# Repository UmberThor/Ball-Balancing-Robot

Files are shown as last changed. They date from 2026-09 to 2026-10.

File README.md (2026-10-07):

# Ball Balancing Robot

A 3-DOF parallel platform that keeps a ball balanced in the center of a transparent plate. A camera looks at the plate from below and detects the position of the ball, a controller turns the ball position error into a desired plate slope, and the inverse kinematics turns that slope into three servo angles.

<p align="center">
  The robot balancing a ball
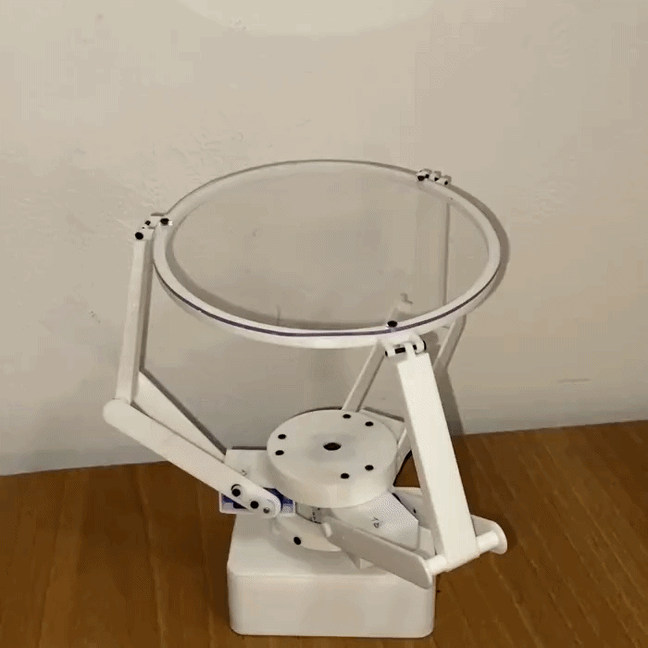
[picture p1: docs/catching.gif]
The robot catching a ball
  
  <br>
  <em>On the left the robot balancing a ball, on the right the robot catching a ball (0.5 speed)</em>
</p>

Three controllers are tested: a PID controller, an LQR controller and an RL controller.

The repository is organized as follows:

```
Ball-Balancing-Robot/
├── scripts/                          code that runs on the robot
│   ├── ball_balancer.py              main loop
│   ├── hardware.py                   servos and camera
│   ├── vision.py                     ball detection
│   ├── kalman.py                     estimate of the error and of its velocity
│   ├── control.py                    PID, LQR and RL controllers
│   ├── kinematics.py                 inverse kinematics
│   └── policy.npz                    weights of the RL policy
├── reinforcement_learning/           simulation and training of the RL controller
│   ├── ball_balancer.xml             MuJoCo model of the plate and the ball
│   ├── ball_balancer_env.py          Gymnasium environment
│   ├── action_limits.ipynb           computation of the action limit
│   ├── reinforcement_learning.ipynb  training of the policy
│   └── environment.yml               conda environment
├── matlab/                           offline references, not run on the robot
│   ├── inverse_kinematics.m          inverse kinematics and plot of the assembly
│   └── linear_quadratic_control.m    computation of the LQR gain
├── metrics/                          evaluation of the controllers
│   ├── metrics.py                    metrics of the logged runs
│   └── log_*.csv                     logged runs
└── 3d files/                         printed parts
```

This README is organized in the following sections:

| § | Section |
|---|---|
| 1 | Running the code |
| 2 | Mechanical design |
| 3 | Electronics |
| 4 | 3D print and assembly |
| 5 | Inverse kinematics |
| 6 | Actuation |
| 7 | Ball detection |
| 8 | Ball model |
| 9 | Kalman filter |
| 10 | PID control |
| 11 | LQR control |
| 12 | Reinforcement learning control |
| 13 | Evaluation metrics |
| 14 | Future developments |
| 15 | Credits |

## 1. Running the code

The code runs on the Raspberry Pi of §3, with Raspberry Pi OS. The dependencies are installed with `apt`, and the `pigpio` daemon must be started before the script.

```bash
sudo apt install git python3-picamera2 python3-opencv python3-numpy pigpio python3-pigpio
git clone https://github.com/UmberThor/Ball-Balancing-Robot.git
cd Ball-Balancing-Robot/scripts
sudo pigpiod
python3 ball_balancer.py --pid
```

Exactly one control mode must be selected:

| Flag | Control |
|---|---|
| `--pid` | Proportional Integral Derivative Controller, §10 |
| `--lqr` | Linear Quadratic Regulator Controller, §11 |
| `--rl` | Reinforcement Learning, §12|

The `--gui` flag is optional and opens a window that shows the ball detection of §7, and requires a display.

The `--kalman` flag is optional and feeds the controller with the error and the velocity estimated by the Kalman filter of §9 instead of the measured error and its finite difference. 

The `--log` flag is optional and, when the script stops, saves to `log_<mode>_<date>_<time>.csv` the time, the measured error and the control action of every frame with the ball. 

The script is stopped with Ctrl+C, or with `q` on the window when `--gui` is set.

---

## 2. Mechanical design

The robot is modeled in Fusion 360.

<p align="center">
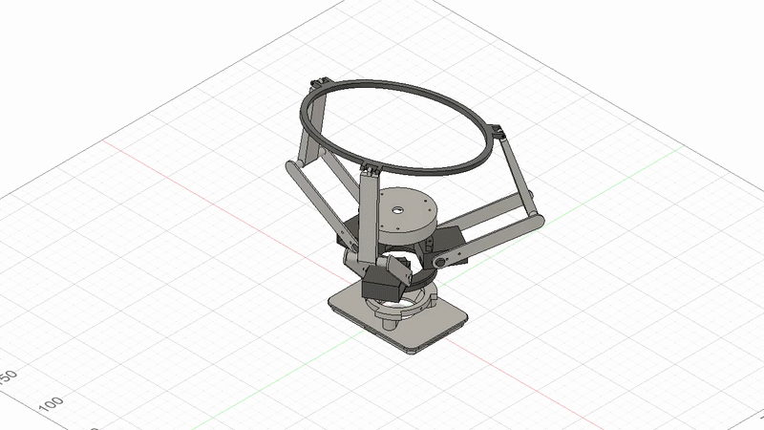
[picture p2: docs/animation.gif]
  
  <br>
  <em>The assembly moving in Fusion 360</em>
</p>

The robot has a fixed base and a moving plate, a printed ring that holds a transparent plexiglass disc. Three identical arms, located 120° apart, connect the base to the plate. Each arm is a two-link RRU chain, so the robot as a whole is a **3-RRU** parallel manipulator: revolute at the shoulder, revolute at the elbow, universal at the ball joint. The shoulder joint is **active**, driven by a servo; the elbow and the ball joint are **passive**. Each arm is carried by the servo horn alone, so it hangs on one side of the servo.

The robot axes have the origin at the center of the base, at the height of the servo shafts, with $z$ vertical and upward, and $x$ horizontal, from the shoulder of arm 1 through the center of the base. Measured from $x$ towards $y$, arm 1 is at 180°, arm 2 at 300° and arm 3 at 60°.

The dimensions of the mechanism, measured on the Fusion 360 model, are:

| Constant | Meaning | Value |
|---|---|---|
| $R_b$ | radius of the base circle, on which the shoulders lie | 28.65 mm |
| $R_p$ | radius of the plate circle, on which the ball joints lie | 84.00 mm |
| $L_1$ | length of the upper link, from the elbow to the ball joint | 80 mm |
| $L_2$ | length of the lower link, from the shoulder to the elbow | 80 mm |

All the printed parts are in the `3d files` folder:

| File | Part | Qty |
|---|---|---|
| `raspberry_bottom.stl` | lower half of the Raspberry Pi case, the foot of the robot | 1 |
| `raspberry_top.stl` | upper half of the case, modified to carry the servo base | 1 |
| `camera_cover.stl` | cover that holds the camera pointing up at the plate | 1 |
| `motor_base.stl` | base that holds the three servos 120° apart | 1 |
| `link_lower_half.stl` | half of the lower link, from the servo to the elbow | 6 |
| `link_lower_connector.stl` | connector of the two halves of the lower link | 3 |
| `link_upper.stl` | upper link, from the elbow to the plate | 3 |
| `plate.stl` | ring that holds the transparent plate | 1 |

> **On the ball joints.** They are *modeled* as ball joints but the printed robot realizes them as a screw through a clearance hole. That is nominally a pin joint; the extra rotational freedom comes from the clearance, so it is a compliant stand-in for a spherical pair rather than a true ball joint.

<p align="center">
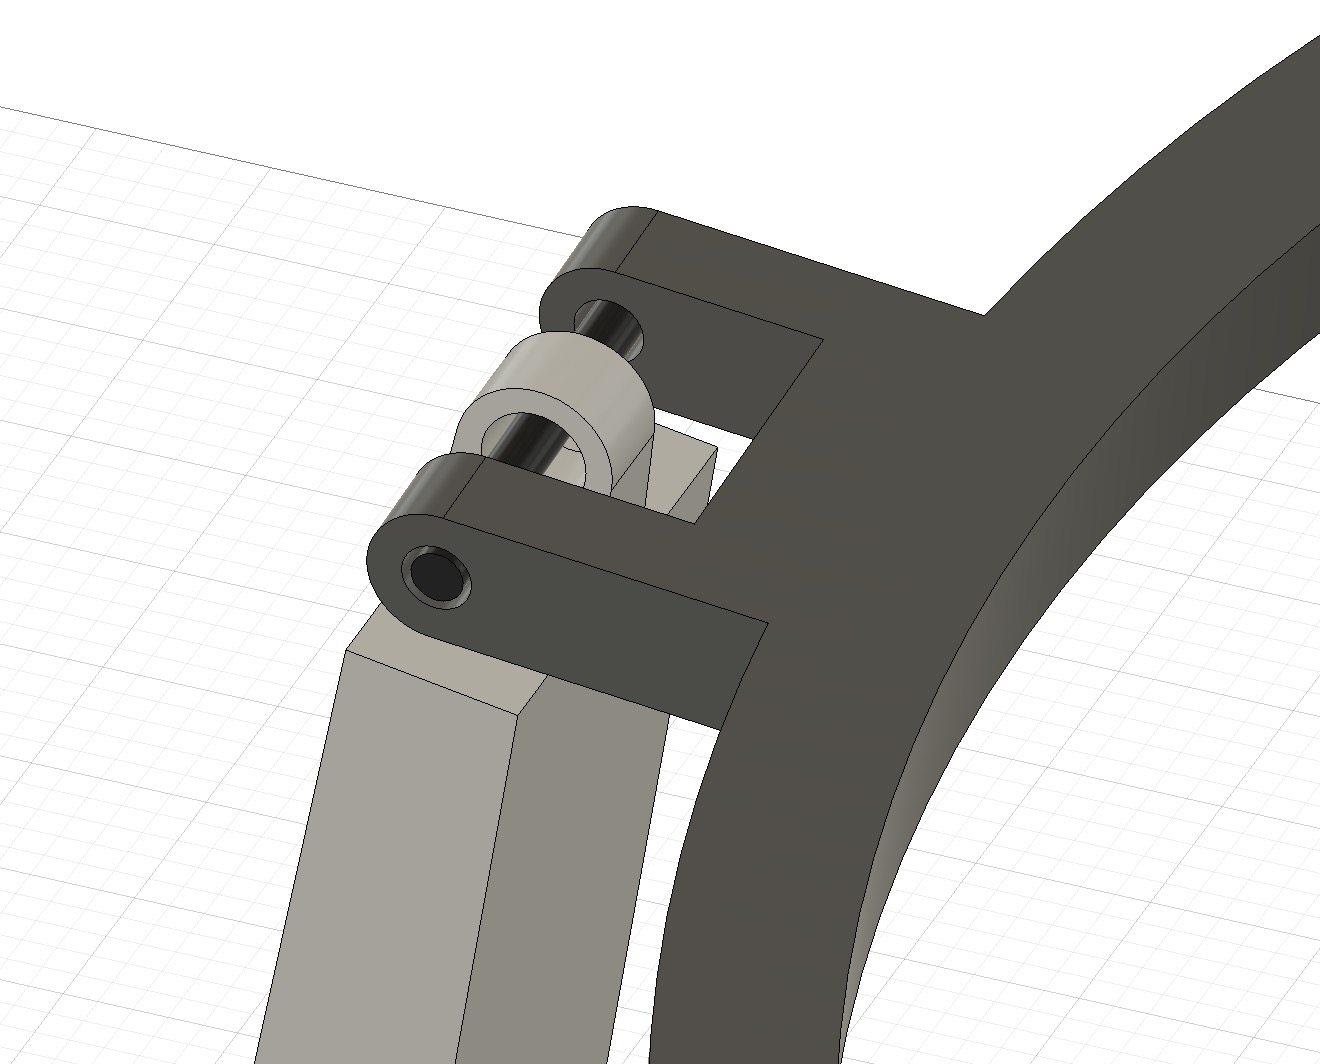
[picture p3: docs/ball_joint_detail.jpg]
  
  <br>
  <em>The joint connecting the upper link with the plate</em>
</p>

In the first version of the robot the links were about half as long as the current ones. The plate was then so close to the camera that the ball covered almost the entire field of view, and its position was detected poorly. The links have therefore been made longer, until the distance between the camera and the plate was enough for a reliable detection, but not so long as to increase excessively the moment arm, and with it the torque the servos need to tilt the plate.

## 3. Electronics

The electronics are kept as simple as possible: a Raspberry Pi 4 Model B, three SG90 servos, a 5 megapixel camera module that plugs into the CSI port of the Raspberry Pi, and male-female jumper cables.

Each servo has three wires: signal, 5V and ground. The signal wires go to three GPIO pins of the Raspberry Pi, and servo $i$ drives arm $i$:

| Servo | GPIO (BCM) |
|---|---|
| 1 | 13 |
| 2 | 18 |
| 3 | 12 |

The numbers are the BCM numbering used by `pigpio`, not the position of the pin on the header. This is also the order declared in `scripts/hardware.py`, so keeping it makes the code work as it is.

The three grounds go to three distinct GND pins. The 5V pins of the Raspberry Pi are only two, so one servo takes one of them, while the other two share the second one through a jumper cable with one female and two male ends, made by hand.

<p align="center">
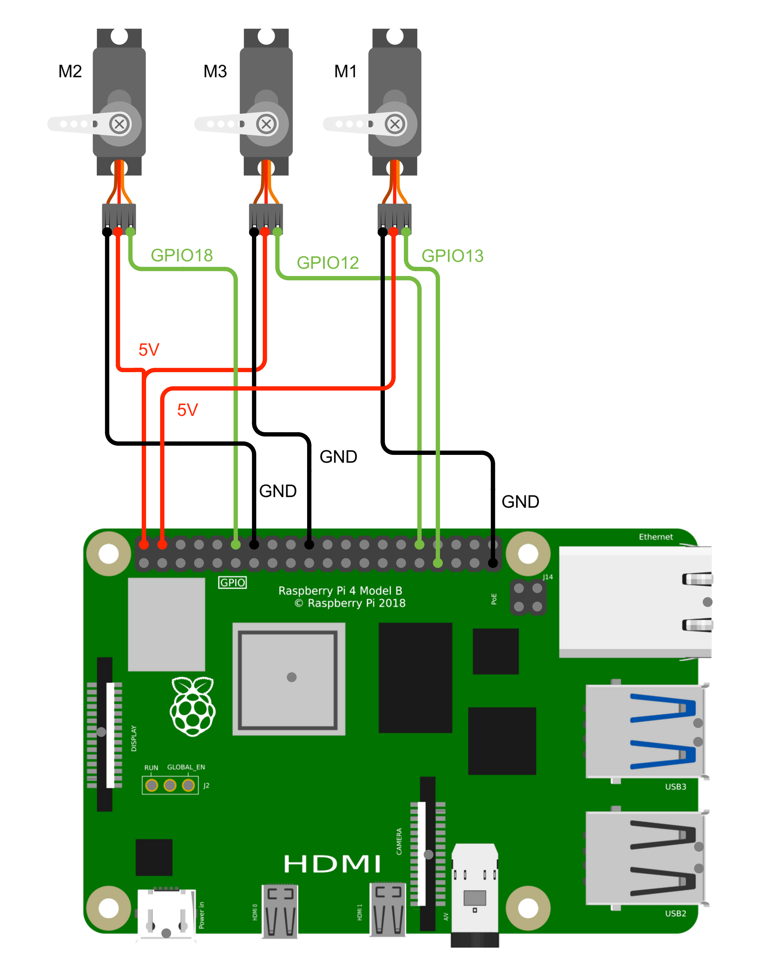
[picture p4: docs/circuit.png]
The three servos wired to the GPIO header of the Raspberry Pi
  
  <br>
  <em>Wiring of the three servos to the pins of the Raspberry Pi header</em>
</p>

> **On the power supply.** The Raspberry Pi is powered by its own USB-C cable, which outputs 5.1 V at 3 A, and the three servos draw from that same rail. This is not the ideal way to feed three servos: a proper build would power them from a dedicated power supply module, leaving the 5V rail of the Raspberry Pi to the Raspberry Pi alone. Compactness was one of the goals of this project, so the current version accepts the compromise.

## 4. 3D print and assembly

### 4.1 3D print

The parts are printed in PLA with the default settings of the slicer. The loads on the structure are low, so orientation and infill are not critical. `motor_base.stl` and `raspberry_top.stl` require supports, `raspberry_bottom.stl` prints better with them but is acceptable without, and the other parts do not need them.

### 4.2 Assembly

Besides the printed parts, the robot needs:

- [Raspberry Pi 4 Model B](https://www.amazon.it/-/en/Raspberry-Pi-W128431608-Model-2GB/dp/B09TTNPB4J)
- [5 megapixel CSI camera module](https://www.amazon.it/dp/B0DKNBP41T?ref=ppx_yo2ov_dt_b_fed_asin_title)
- [30 cm wide flex cable](https://www.amazon.it/dp/B075PBTQPG?ref=ppx_yo2ov_dt_b_fed_asin_title&th=1) for the camera
- 9 male-female jumper cables
- 3 SG90 servos, with their horns and the small screw that fixes each horn to its shaft
- 3 M2 screws 15 mm long, for the ball joints between the upper links and the ring
- 9 M2 screws 4 mm long, six to fix the lower links to the servo horns, two per horn, and three to fix the plate to the ring
- 9 M2 screws 10 mm long, six between the camera cover and the servo base and three between the servo base and the top half of the Raspberry Pi case
- a plexiglass disc of 150 mm of diameter for the plate
- a ping pong ball, pink in this build: a ball of a different color requires the detection of §7 to be adjusted

The horns are mounted with the servos at 90°: each servo is driven to that position before its horn is fixed to the shaft, aligned with the body of the servo. The alignment is necessarily approximate: what is left of it is corrected in software by the constants `OFFSETS` of `scripts/hardware.py`, `[0, -5, -5]` in this build, which are added in degrees to the angles commanded to the three servos.

<p align="center">
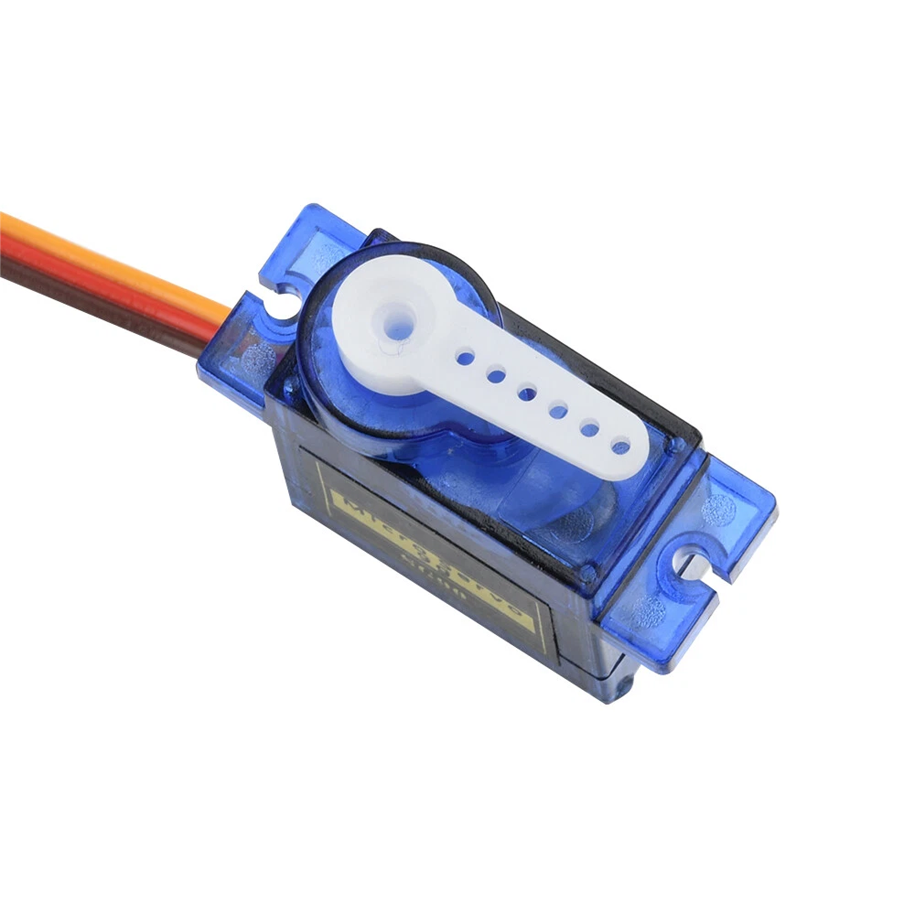
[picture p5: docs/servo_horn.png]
Servo horn aligned with the body of the servo
  
  <br>
  <em>Position of the horn at 90°</em>
</p>

## 5. Inverse kinematics

Reference implementation: `matlab/inverse_kinematics.m`.

### 5.1 Problem statement

In the model, the plate is a rigid disc whose center is constrained to the vertical $z$ axis. It can therefore only *tilt* and *rise*, which is exactly 3 DOF.

The **pose** of the plate is given by:

- $\mathbf{n} = [n_x,\ n_y,\ n_z]^T$, the unit normal of the plate,
- $h$, the height of the center of the plate $(0, 0, h)$, in mm.

The **configuration** of the robot is given by the three servo angles $q_1, q_2, q_3$. The inverse kinematics computes the configuration from the pose.

### 5.2 Geometry

| Point | Meaning |
|---|---|
| $\mathbf{M}_i$ | coordinates of the $i$-th shoulder, on the base circle of radius $R_b$ |
| $\mathbf{P}_i$ | coordinates of the $i$-th elbow, which connects the two links |
| $\mathbf{B}_i$ | coordinates of the $i$-th ball joint, on the plate circle of radius $R_p$ |

The constants $R_b$, $R_p$, $L_1$ and $L_2$ are the ones of §2. Running `inverse_kinematics.m` draws the whole assembly for a given pose:

<p align="center">
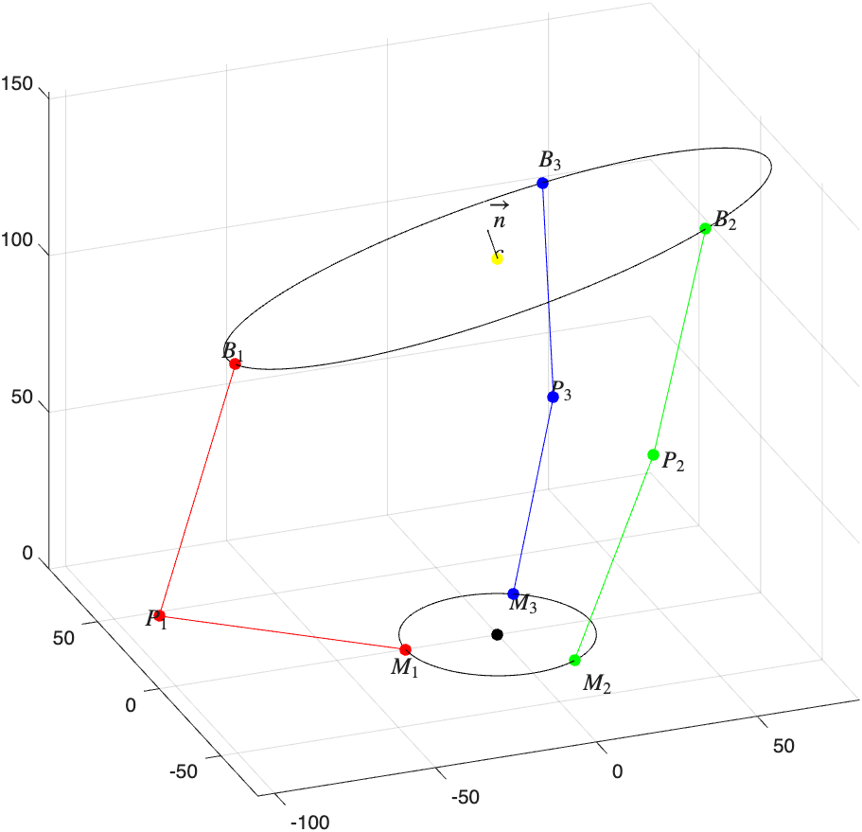
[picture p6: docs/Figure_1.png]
  
  <br>
  <em>The assembly for <b>n</b> = [&minus;0.25, 0.33, 1]<sup>T</sup>, plotted by <code>inverse_kinematics.m</code>: base circle and the three shoulders, plate circle with its normal arrow, ball joints, elbows and both links of every arm, red / green / blue for arms 1 / 2 / 3</em>
</p>

### 5.3 Planes

Each arm ($\mathbf{M}_i$, $\mathbf{P}_i$ and $\mathbf{B}_i$) is confined to a fixed vertical plane. In coordinates, that plane is simply

$$y = E_i\  x .$$

where $E_i = \frac{M_{iy}}{M_{ix}}$. Under this consideration, the entire 3D problem collapses into three independent 2D problems, one per plane.

<p align="center">
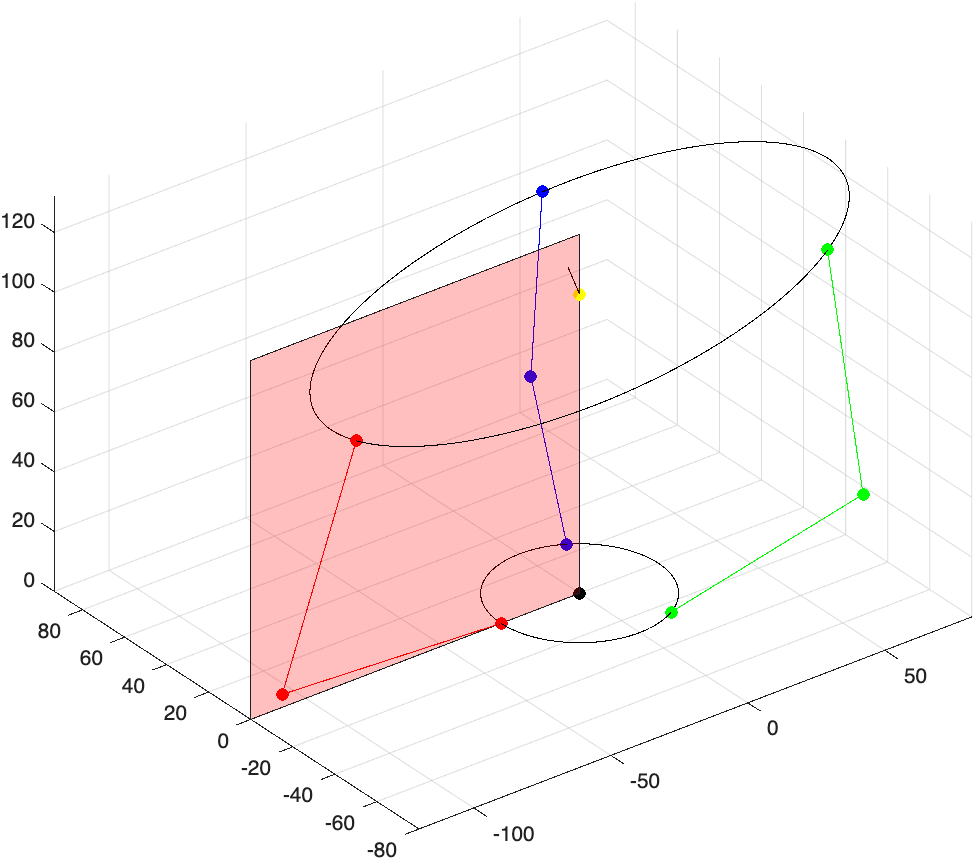
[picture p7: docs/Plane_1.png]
Plane y = 0 containing arm 1
  
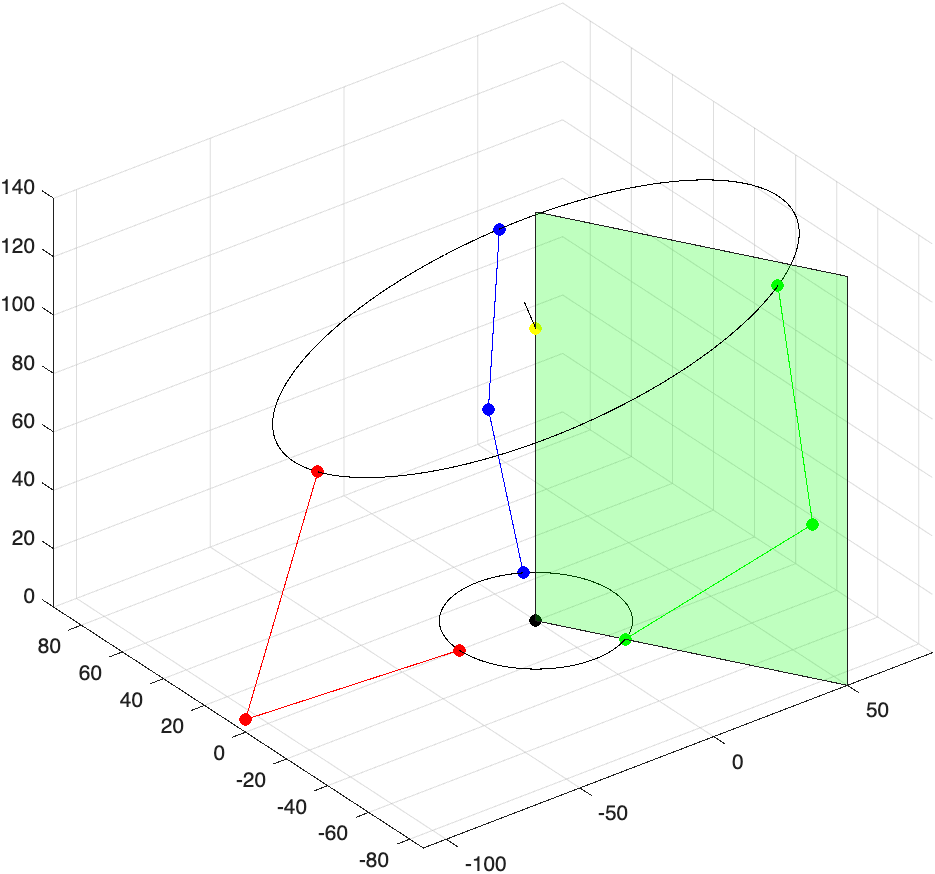
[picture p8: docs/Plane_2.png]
Plane y = -sqrt(3) x containing arm 2
  
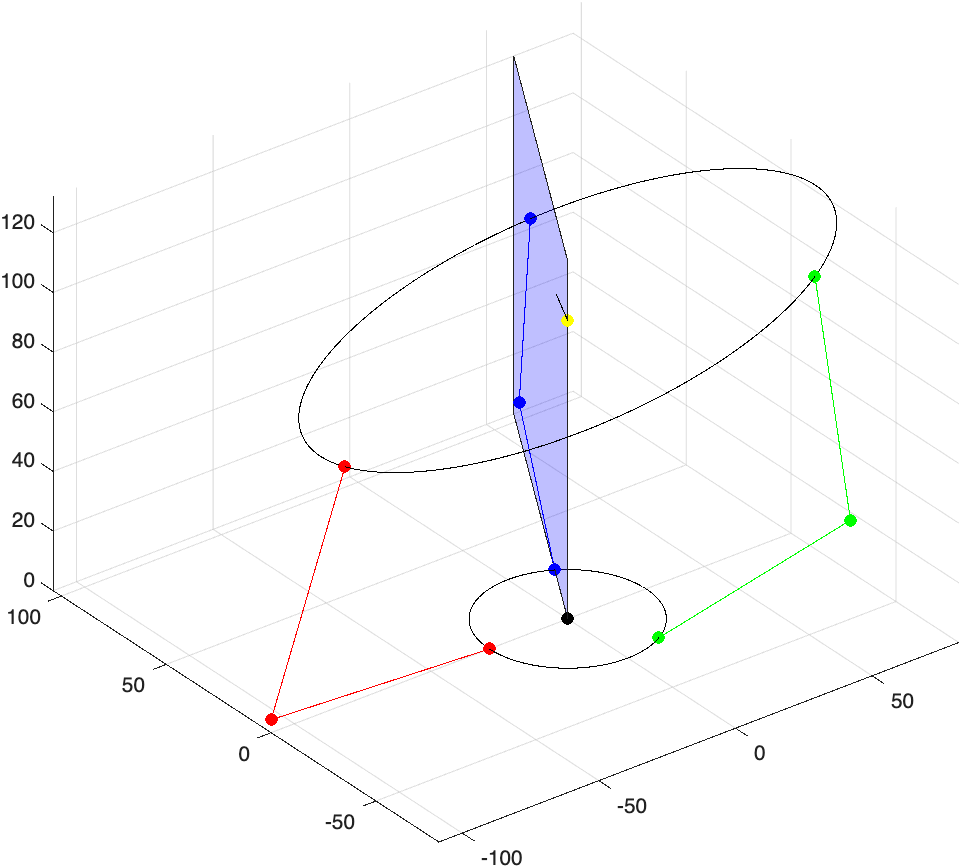
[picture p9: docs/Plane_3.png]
Plane y = sqrt(3) x containing arm 3
  
  <br>
  <em>The three arm planes: arm 1 is red, arm 2 is green and arm 3 is blue.<br>Whatever the pose of the plate, each arm and the ball joint it drives stay in their own plane.</em>
</p>

The shoulders lie on the base circle of radius $R_b$, at the angles of §2, so:

| Arm | $\mathbf{M}_i$ | $E_i$
|-----|---|---|
| 1 | $(-R_b,\ 0,\ 0)$ | $0$
| 2 | $(R_b/2,\ -\tfrac{\sqrt3}{2}R_b,\ 0)$ | $-\sqrt3$ |
| 3 | $(R_b/2,\ +\tfrac{\sqrt3}{2}R_b,\ 0)$ | $+\sqrt3$ |

### 5.4 Step 1 — Ball joints $\mathbf{B}_i$

$\mathbf{B}_i$ is the intersection of three conditions:

1. it lies in the plane of the plate
2. it lies in the arm plane
3. it lies on the circle of the ball joints

This leads to writing the system:

$$
\begin{cases}
n_x x + n_y y + n_z (z - h)= 0 \\
y = E_i x \\
x^2 + y^2 + (z - h)^2 = R_p^2
\end{cases}
$$

Substituting (2) into (1) gives the height along the plane as a function of $x$:

$$z = h - \frac{n_x + n_y E_i}{n_z}\ x$$

and substituting both into (3) leaves a pure quadratic in $x$:

$$x^2\left[1 + E_i^2 + \frac{(n_x + n_y E_i)^2}{n_z^2}\right] = R_p^2 .$$

Hence the closed form for any arm:

$$
x_i = s_i\ \frac{n_z R_p}{\sqrt{n_z^2\left(1 + E_i^2\right) + (n_x + n_y E_i)^2}},
\qquad y_i = E_i\ x_i,
\qquad z_i = h - \frac{n_x + n_y E_i}{n_z}\ x_i$$

where $s_i \in \lbrace -1, +1 \rbrace$ picks the one of the two points of the plate circle that is on the side of the shoulder; the other root is the diametrically opposite point of the circle.

Expanding for the three arms gives:

**Arm 1**: $E_1 = 0$, $s_1 = -1$:

$$\mathbf{B}_1 = \left(-\frac{n_z R_p}{\sqrt{n_x^2 + n_z^2}},\quad 0,\quad
h + \frac{n_x R_p}{\sqrt{n_x^2 + n_z^2}}\right)$$

**Arm 2**: $E_2 = -\sqrt3$, $s_2 = +1$:

$$\mathbf{B}_2 = \left(
\frac{n_z R_p}{\sqrt{4n_z^2 + \left(\sqrt3n_y - n_x\right)^2}},\quad
-\frac{\sqrt3\ n_z R_p}{\sqrt{4n_z^2 + \left(\sqrt3n_y - n_x\right)^2}},\quad
h + \frac{R_p\left(\sqrt3n_y - n_x\right)}{\sqrt{4n_z^2 + \left(\sqrt3n_y - n_x\right)^2}}
\right)$$

**Arm 3**: $E_3 = +\sqrt3$, $s_3 = +1$:

$$\mathbf{B}_3 = \left(
\frac{n_z R_p}{\sqrt{4n_z^2 + \left(\sqrt3n_y + n_x\right)^2}},\quad
+\frac{\sqrt3\ n_z R_p}{\sqrt{4n_z^2 + \left(\sqrt3n_y + n_x\right)^2}},\quad
h - \frac{R_p\left(\sqrt3n_y + n_x\right)}{\sqrt{4n_z^2 + \left(\sqrt3n_y + n_x\right)^2}}
\right)$$

Before solving for the elbow, the two-link chain must be able to span the gap between shoulder and ball joint. The triangle inequality gives, per arm,

$$|L_1 - L_2| < \lVert \mathbf{B}_i - \mathbf{M}_i \rVert < L_1 + L_2$$

If such condition fails, the requested pose $(\mathbf{n}, h)$ is simply not reachable.

### 5.5 Step 2 — Elbows $\mathbf{P}_i$

$\mathbf{P}_i$ is again the intersection of three conditions:

1. it is at distance $L_1$ from the ball joint
2. it is at distance $L_2$ from the shoulder
3. it lies in the arm plane

This leads to writing the system:

$$
\begin{cases}
(x - B_{ix})^2 + (y - B_{iy})^2 + (z - B_{iz})^2 = L_1^2 \\
(x - M_{ix})^2 + (y - M_{iy})^2 + (z - M_{iz})^2 = L_2^2 \\
y = E_i x
\end{cases}
$$

Subtracting sphere (2) from sphere (1) kills every quadratic term and leaves a plane, which solved for $z$ reads

$$z = \lambda_i + \mu_ix + \nu_iy$$

with

$$
\begin{gathered}
\lambda_i = \frac{L_1^2 - L_2^2 + \left(M_{ix}^2 - B_{ix}^2\right) + \left(M_{iy}^2 - B_{iy}^2\right) + \left(M_{iz}^2 - B_{iz}^2\right)}{2 (M_{iz} - B_{iz})} \\
\mu_i = \frac{B_{ix} - M_{ix}}{M_{iz} - B_{iz}} \\
\nu_i = \frac{B_{iy} - M_{iy}}{M_{iz} - B_{iz}}
\end{gathered}
$$

Geometrically this is the *radical plane* of the two spheres: the plane that contains their intersection circle. Intersecting it with $y = E_i x$ collapses the circle to the two points of a line:

$$y = E_i x, \qquad z = \lambda_i + (\mu_i + \nu_i E_i)\ x$$

Putting the line back into condition (1) gives

$$\underbrace{\left[1 + E_i^2 + (\mu_i + \nu_iE_i)^2\right]}_{a_{2i}}x^2 +
\underbrace{\left[-2B_{ix} - 2E_iB_{iy} + 2(\mu_i + \nu_iE_i)(\lambda_i - B_{iz})\right]}_{a_{1i}}x +
\underbrace{\left[B_{ix}^2 + B_{iy}^2 + (\lambda_i - B_{iz})^2 - L_1^2\right]}_{a_{0i}} = 0$$

$$x = \frac{-a_{1i} \pm \sqrt{a_{1i}^2 - 4a_{2i}a_{0i}}}{2a_{2i}}$$

The two roots are the two physical assemblies of the arm: elbow folded outward and elbow folded inward. The robot is built with the elbow out, so the root to keep is the one that maximizes $|x|$: that is the $+$ root when $s_i = +1$ and the $-$ root when $s_i = -1$.

<p align="center">
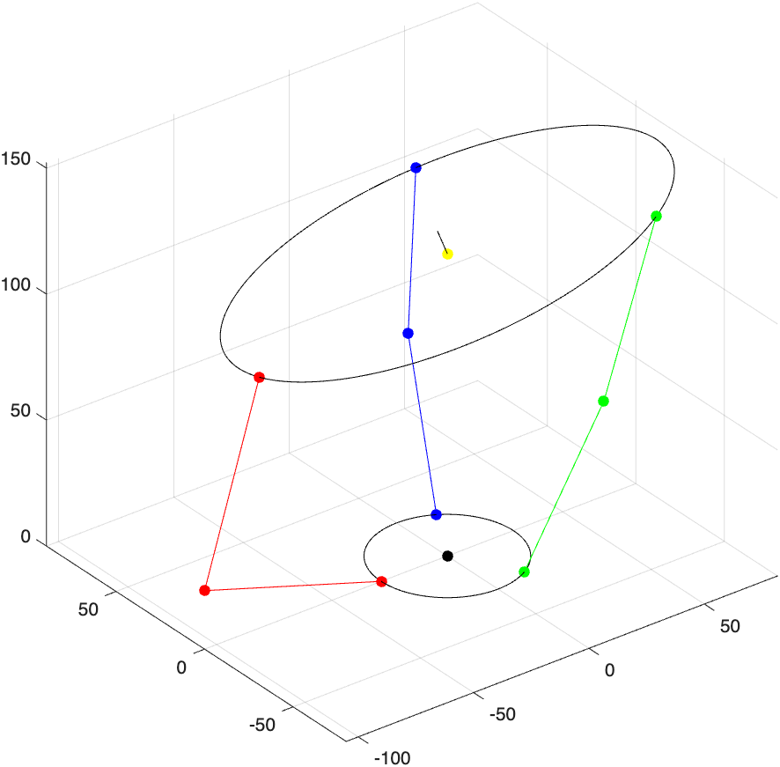
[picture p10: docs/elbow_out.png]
Elbow out configuration
  
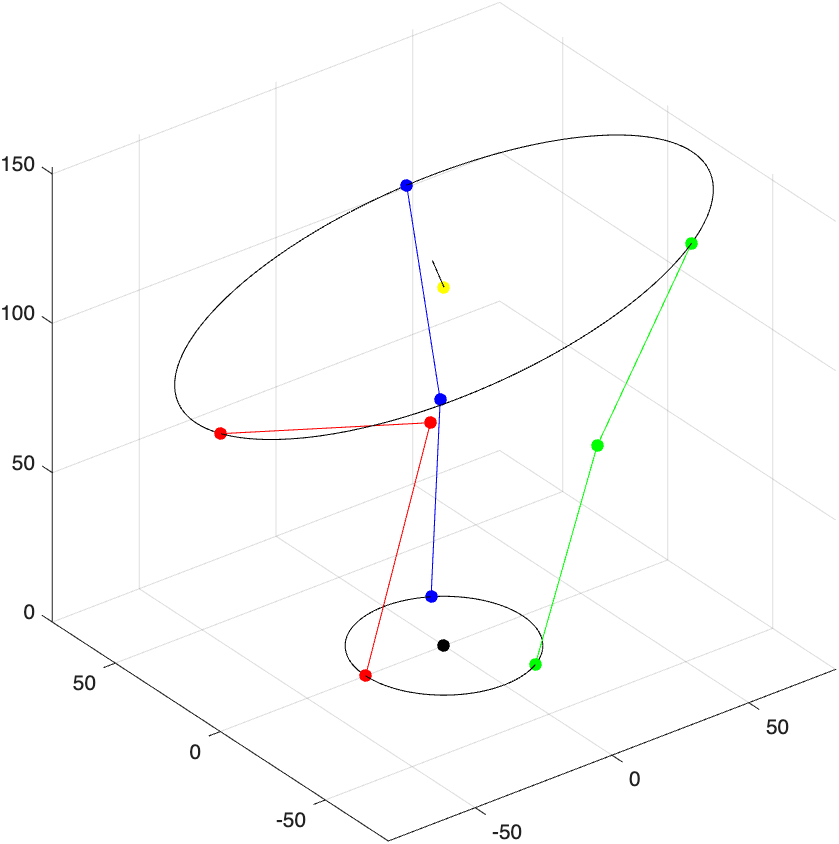
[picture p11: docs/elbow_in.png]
Elbow in configuration
  
  <br>
  <em>The two roots of the quadratic, for the same pose of the plate: on the left the elbow out configuration, the one the robot is built with, on the right the elbow in one, which is discarded.</em>
</p>

Once $x$ is found, the coordinates of the $i$-th elbow are:

$$ \mathbf{P}_i = \Big(x,\quad E_i x,\quad \lambda_i + (\mu_i + \nu_iE_i)\ x\Big)$$

### 5.6 Step 3 — Servo angles $q_i$

The servo angle is the angle of the lower link ($\mathbf{M}_i \to \mathbf{P}_i$) measured from the vertical.

$$q_i = \arctan\left(\frac{\sqrt{(P_{ix} - M_{ix})^2 + (P_{iy} - M_{iy})^2}}{\lvert P_{iz} - M_{iz}\rvert}\right)$$

The angle commanded to servo $i$ is $q_i$: at $q_i = 90°$ the lower link is horizontal, and the horn is in the position of §4.2.

### 5.7 Worked example

For $\mathbf{n} = [-0.25, 0.33, 1]^T$, $h = 100$ mm, with the constants of §2:

| Arm | $\mathbf{B}_i$ | $\mathbf{P}_i$ | $q_i$ |
|---|---|---|---|
| 1 | $(-81.49,\ 0,\ 79.63)$ | $(-108.53,\ 0,\ 4.34)$ | $86.89°$ |
| 2 | $(38.85,\ -67.29,\ 131.92)$ | $(44.42,\ -76.94,\ 52.70)$ | $48.80°$ |
| 3 | $(41.47,\ 71.82,\ 86.67)$ | $(53.97,\ 93.47,\ 10.67)$ | $82.33°$ |

## 6. Actuation

The control action $\mathbf{u}$ is the **slope** of the plate, a dimensionless vector of the horizontal plane, imposed on the plate as the direction of steepest descent of its surface: the plate is tilted so that a ball resting on it rolls, and accelerates, along $\mathbf{u}$. A surface of gradient $\nabla z = (a,\ b)$ has upward normal $[-a,\ -b,\ 1]$, so imposing $\mathbf{u} = -\nabla z$ means giving the plate the normal

$$\mathbf{n} = \frac{[u_x,\ u_y,\ 1]}{\lVert [u_x,\ u_y,\ 1] \rVert}$$

at the fixed height $h = 120$ mm. The pose is therefore also given by $(u_x,\ u_y,\ h)$, and §5 turns it into the configuration. The nominal pose is $\mathbf{u} = 0$, $h = 120$ mm, which gives $q_1 = q_2 = q_3 \approx 59°$.

§5 returns the configuration of every reachable pose, including the ones that need $q > 90°$. The robot never uses them: to balance the ball the plate must stay close to horizontal. The servo angles are therefore clipped to the travel $[45°,\ 75°]$, about $\pm 15°$ around the nominal pose: enough travel to correct the position of the ball, and never enough to reach a configuration that the robot cannot assume. The clipped angles are then shifted by the offsets of §4.2. A pose that §5 finds unreachable is skipped, so the servos hold the previous command.

The three servos are driven by `pigpio`, which times the pulses with DMA, independently of the Python loop. Each servo receives a pulse every 20 ms, and the width of the pulse sets its angle, from 500 µs at 0° to 2500 µs at 180°. At startup the servos are driven to the nominal pose, and at shut down the pulses are stopped, which leaves the servos free.

## 7. Ball detection

The ball is detected by color in `scripts/vision.py`, on frames of 320 by 240 pixels. The camera runs at 20 Hz, which sets the rate of the loop. The camera is centered under the plate, with the axes of the image parallel to the axes $x$ and $y$ of §2, so the center of the frame is the center of the plate.

Each frame is converted to HSV and thresholded with hue from 148 to 180, saturation of at least 110 and value of at least 50. A ball of a different color requires a different range. The mask is cleaned with a morphological opening and closing, and its largest contour is accepted as the ball if its area is large enough and it fills more than 50% of its minimum enclosing circle. The center and the radius of that circle are the output of the detection. The position error $\mathbf{e}$, input of the controller, is the vector from the ball to the center of the frame, in pixels.

<p align="center">
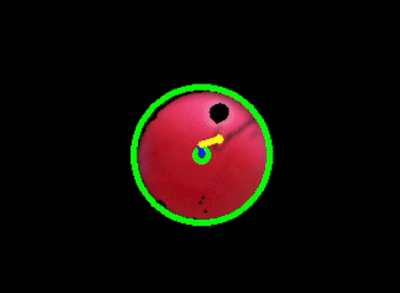
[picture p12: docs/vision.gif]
The masked frame shown by the --gui window
  
  <br>
  <em>The window of <code>--gui</code>: the frame masked by the detection, with the enclosing circle of the ball and its center in green, the vector from the center of the frame to the ball in blue and the control action, scaled, in yellow</em>
</p>

## 8. Ball model

The Kalman filter of §9, the LQR of §11 and the simulation of §12 use the same model of the ball. The ball, of mass $m$, radius $r$ and moment of inertia $I$, rolls without slipping on the plate tilted by $\theta$.

<p align="center">
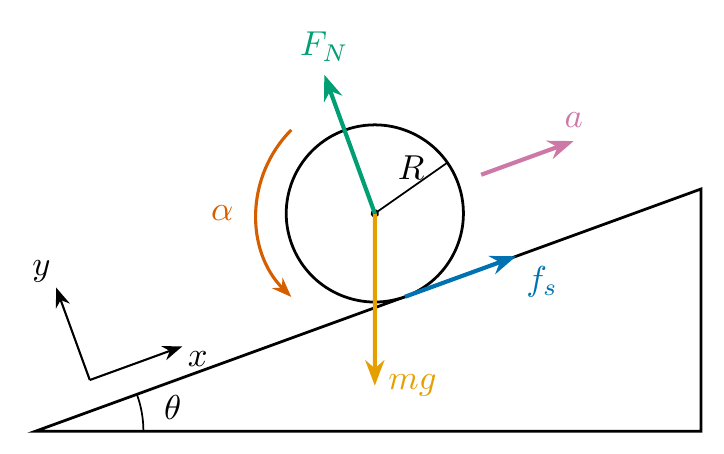
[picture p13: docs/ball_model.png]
Free body diagram of the ball on the tilted plate
  
  <br>
  <em>Free body diagram of the ball on the plate tilted by &theta;, with the <i>x</i> axis along the slope and &alpha; positive counterclockwise</em>
</p>

Along $x$ and about the center of the ball, gravity and the static friction $f_s$ give:

$$
\begin{gathered}
f_s - m g \sin\theta = m \ddot x \\
I \alpha = r f_s
\end{gathered}
$$

The rolling condition $\alpha = -\ddot x / r$ eliminates $f_s$. A ping pong ball is a hollow sphere, $I = \frac{2}{3} m r^2$, so:

$$\ddot x = -\frac{g \sin\theta}{1 + \frac{I}{m r^2}} = -\frac{3}{5} g \sin\theta$$

For small tilts $\sin\theta \approx \tan\theta = \lVert \mathbf{u} \rVert$, so the ball accelerates along $\mathbf{u}$ by $\frac{3}{5} g \lVert \mathbf{u} \rVert$. The error points from the ball to the center of the frame, so, in pixels, with the scale $\rho = 2500$ px/m given by the ball radius of 50 px and 0.02 m, each axis follows

$$\ddot e = c u, \qquad c = -\frac{3}{5} g \rho = -14715\ \mathrm{px/s^2}$$

## 9. Kalman filter

The PID of §10 and the LQR of §11 need the error and its velocity. Without `--kalman`, they use the error $\mathbf{e}$ measured in §7 and its finite difference, which amplifies the noise of the detection. With `--kalman`, they use the error and the velocity estimated by the Kalman filter in `scripts/kalman.py`.

Each axis is treated separately, with the model of §8: the state is the error $e$ and its velocity $\dot e$, and the input is the slope $u$ of the plate along that axis. The state $\boldsymbol{\xi}_k = [e,\ \dot e]^T$ is the state at frame $k$. The slope $u_k$ is commanded at frame $k$ and does not change until frame $k+1$. $dt$ is the measured time from frame $k$ to frame $k+1$:

```math
\boldsymbol{\xi}_{k+1} =
\underbrace{\begin{bmatrix} 1 & dt \\ 0 & 1 \end{bmatrix}}_{F}
\boldsymbol{\xi}_k +
\underbrace{\begin{bmatrix} c\ dt^2/2 \\ c\ dt \end{bmatrix}}_{G} u_k +
\mathbf{w}_k
```

where $\mathbf{w}_k$ is the acceleration the model does not explain, such as friction, servo lag and pushes, taken as random with standard deviation $\sigma_a = 100$ px/s²:

```math
Q_w = \sigma_a^2 \begin{bmatrix} dt^4/4 & dt^3/2 \\ dt^3/2 & dt^2 \end{bmatrix}
```

Only the error is measured: the measurement is $e_m = \mathbf{m}\boldsymbol{\xi}$, with $\mathbf{m} = [1,\ 0]$ and variance $\sigma_m^2 = 1$ px². Each frame predicts the state with the model and corrects it with the measured error $e_m$:

$$
\begin{gathered}
\hat{\boldsymbol{\xi}}^- = F \hat{\boldsymbol{\xi}} + G u, \qquad \Sigma^- = F \Sigma F^T + Q_w \\
S = \mathbf{m} \Sigma^- \mathbf{m}^T + \sigma_m^2, \qquad \mathbf{k}_f = \Sigma^- \mathbf{m}^T / S \\
\hat{\boldsymbol{\xi}} = \hat{\boldsymbol{\xi}}^- + \mathbf{k}_f \left(e_m - \mathbf{m}\hat{\boldsymbol{\xi}}^-\right), \qquad \Sigma = (I - \mathbf{k}_f \mathbf{m}) \Sigma^-
\end{gathered}
$$

where $\hat{\boldsymbol{\xi}} = [\hat e,\ \hat{\dot e}]^T$ is the estimate, $\Sigma$ its covariance and $\mathbf{k}_f$ the gain of the filter. $\Sigma$ does not depend on the measurements, so a single one serves both axes.

## 10. PID control

The PID is in `scripts/control.py` and is selected with `--pid`. Each axis is controlled separately, with the same gains:

$$\mathbf{u} = K_p \mathbf{e} + K_i \int \mathbf{e}\ dt + K_d \frac{d \mathbf{e}}{dt}$$

with $K_p = 36 \cdot 10^{-5}$, $K_i = 36 \cdot 10^{-5}$ and $K_d = 20 \cdot 10^{-5}$. The gains convert pixels into slope. The interval $dt$ is measured on every frame. When the ball is reacquired after being lost, the integral and the previous error are reset.

## 11. LQR control

The LQR is in `scripts/control.py` and is selected with `--lqr`. Each axis is controlled separately, with the same gain, computed offline in `matlab/linear_quadratic_control.m`.

### 11.1 Model

The state is the error, its velocity and its integral $e_I = \int e\ dt$, and with the model of §8:

```math
\frac{d}{dt} \begin{bmatrix} e \\ \dot e \\ e_I \end{bmatrix} =
\begin{bmatrix} 0 & 1 & 0 \\ 0 & 0 & 0 \\ 1 & 0 & 0 \end{bmatrix}
\begin{bmatrix} e \\ \dot e \\ e_I \end{bmatrix} +
\begin{bmatrix} 0 \\ c \\ 0 \end{bmatrix} u
```

which is controllable for any $c \neq 0$.

### 11.2 Gain and control law

The model is discretized with a zero order hold at $T_s = 1/20$ s, the period of the loop, and $K$ is the gain of the discrete LQR. The weights follow Bryson's rule:

$$Q = \mathrm{diag}\left(\frac{1}{\bar e^2},\ \frac{1}{\bar{\dot e}^2},\ \frac{1}{\bar e_I^2}\right), \qquad R = \frac{1}{\bar u^2}$$

with the largest acceptable values $\bar e = 50$ px, $\bar{\dot e} = 100$ px/s, $\bar e_I = 200$ px·s and $\bar u = 0.0175$, a slope of 1°. The resulting gain is

$$K = [-3.756 \cdot 10^{-4},\quad -2.744 \cdot 10^{-4},\quad -7.830 \cdot 10^{-5}]$$

and the control law is

$$\mathbf{u} = -K [\mathbf{e},\ \dot{\mathbf{e}},\ \mathbf{e}_I]^T$$

## 12. Reinforcement learning control

The neural network trained with RL, the policy, is in `scripts/control.py` and is selected with `--rl`. It is trained in a simulation of the robot, and only the trained network runs on the Raspberry Pi. Everything about the training is in the `reinforcement_learning` folder.

### 12.1 Simulation

The robot is simulated in MuJoCo, in `ball_balancer.xml`, and wrapped in a Gymnasium environment, `ball_balancer_env.py`. Only the plate and the ball are simulated. The physics advances by 25 steps of 2 ms for each control step, which gives the 20 Hz of the loop of §7.

What the policy commands is the quantity of the robot. The action is the slope of the plate, $\mathbf{u} = U_{max} \mathbf{a}$ with $\mathbf{a} \in [-1, 1]^2$ and $U_{max} = 0.14$, the largest value for which no action of the square leaves the travel $[45°,\ 75°]$ of §6, computed in `action_limits.ipynb`.

<p align="center">
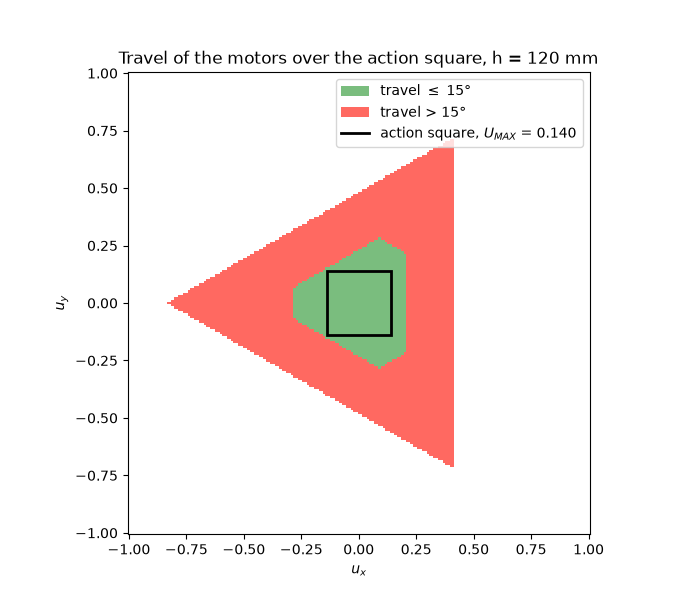
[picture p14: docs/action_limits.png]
Travel of the servos over the square of the actions
  
  <br>
  <em>Travel of the servos over the plane of the slopes: green where no servo leaves its travel, red beyond it, white where the pose is unreachable. The square is the one of the actions</em>
</p>

The action then goes through the same chain as the output of the PID: §6 turns it into a pose and §5, with the same `kinematics.py` that runs on the robot, into a configuration, which is clipped to the travel. Between the command and the plate the simulation reproduces what the servos add: a first order lag with a rate limit, and a dead band, below which the servo ignores a command, that also stands for the backlash of its gears. The dead band is what makes the ball oscillate around the center instead of settling on it.

The configuration reached by the servos is then turned back into the pose of the plate, at which the plate is driven through its three joints. This forward kinematics is solved with a quasi-Newton method. The Jacobian $J$ of the inverse kinematics, from the pose $(u_x,\ u_y,\ h)$ to the configuration $(q_1,\ q_2,\ q_3)$, is precomputed around the nominal pose: it tells how much the configuration changes in response to a small change of the pose. Its inverse $J^{-1}$ tells how much the pose changes in response to a small change of the configuration, and corrects the pose at each iteration by $J^{-1}$ times the difference between the configuration of the servos and the one §5 gives for the current pose. It is Newton's method applied to the forward kinematics, with the Jacobian fixed at the nominal pose.

The latency of the loop, the time constant of the servos, the noise of the detection and the scale of the camera are drawn at every reset, so that the policy is trained on a family of robots rather than on one:

| Parameter | Nominal | Range |
|---|---|---|
| dead band of the servos | 2.0° | 1.5° to 2.5° |
| latency of the loop | 0.06 s | 0.04 s to 0.10 s |
| time constant of the servos | 0.025 s | 0.015 s to 0.05 s |
| noise of the detection | 2 px | 0.5 px to 2 px |
| scale of the camera | 2500 px/m | ±10% |

<p align="center">
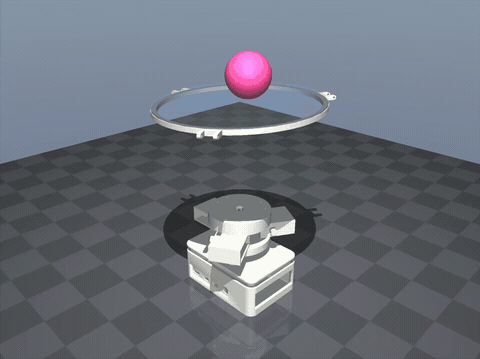
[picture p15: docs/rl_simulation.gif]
The trained policy balancing the ball in simulation
  
  <br>
  <em>The trained policy balancing the ball in the simulation: the arms are not simulated, so the plate floats above the base</em>
</p>

### 12.2 Policy

The velocity of the ball is not measured, so the observation carries a history: the last 6 errors, divided by half the width of the frame, and the last 3 actions, 18 numbers in all. The actions are part of the observation because the delay hides their effect: the frame the policy sees is older than the slope the plate already has.

The reward keeps the ball at the center without asking the servos for more than they can do:

$$r = 1 - \frac{\lVert \mathbf{e} \rVert}{120\ \mathrm{px}} - 0.1 \lVert \mathbf{a} \rVert^2 - 5 \lVert \mathbf{a} - \mathbf{a}_{prev} \rVert^2$$

where $\mathbf{e}$ is the error of §7. The last term penalizes the change of the action, because a chattering command wears the servos without moving the ball. An episode ends when the ball leaves the frame, or after 400 steps, 20 s.

<p align="center">
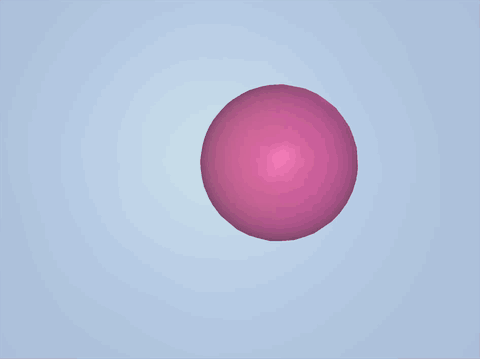
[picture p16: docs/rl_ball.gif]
The simulated frame from which the position of the ball is measured
  
  <br>
  <em>The simulated camera looking up at the plate, the frame on which the error <b>e</b> is measured</em>
</p>

The policy is trained for 100 000 steps with SAC, from `stable-baselines3`, in `reinforcement_learning.ipynb`, where the PID and the LQR of `scripts/control.py` are also run in the simulation as a reference. The network is the default of the library: two hidden layers of 256 units with ReLU, and a tanh on the output.

### 12.3 On the robot

Only the actor is deployed. Its weights are exported to `scripts/policy.npz`, and `control.rl` evaluates the network, 18 → 256 → 256 → 2, in NumPy, so the Raspberry Pi does not need PyTorch. The function keeps the history of errors and actions that the observation needs, and it is reset with the rest of the control when the ball is reacquired.

## 13. Evaluation metrics

The three controllers are compared on the robot, on a run of 60 s each. Running `ball_balancer.py` with `--log` writes a csv with the time, the error and the control action of every frame in which the ball is seen, and `metrics/metrics.py` reduces one or more of those files to four numbers.

The first 5 s of each run are discarded, since they are the transient of the acquisition. 

| Metric | Meaning |
|---|---|
| err mean | Distance of the average position of the ball from the center of the plate |
| err std | Spread of the ball around its average position |
| u mean | Average slope given to the plate |
| du mean | Average change of the slope between two consecutive frames |

| Run | err mean [mm] | err std [mm] | u mean [°] | du mean [°] |
|---|---|---|---|---|
| PID, §10 | 1.4 | 19.4 | 2.32 | 0.31 |
| LQR, §11 | 4.6 | 16.9 | 2.91 | 0.46 |
| RL, §12 | 29.3 | 19.0 | 4.52 | 1.73 |

The PID and the LQR keep the ball on the plate for the whole run, while the RL policy drops it twice and needs it to be put back. The PID centers the ball with the smallest and quietest command. The LQR holds it slightly off center and is a little more active, but its spread is the smallest of the three. The RL policy settles about 3 cm from the center, with a slope twice as large and a change of slope between frames more than five times as large.

In simulation the same RL policy never loses the ball and holds it at the center, so the gap is in the simulation itself: it remains too ideal and does not capture the whole dynamics of the robot, above all the play of the ball joints and the arms carried on one side of the servos (§2). The policy exploits a plate that answers better than the real one, and on the robot that margin is not there.

## 14. Future developments

**Mechanics and electronics**

- A dedicated power supply for the servos, instead of the 5V rail of the Raspberry Pi.
- True spherical joints in place of the screws through clearance holes, whose play is not in the model.
- Metal gear or digital servos in place of the SG90, which have plastic gears, backlash and a coarse resolution.
- Servos with a double shaft, which hold each arm on both sides.

**Control**

- A model of the lag introduced by the servos and by the processing of the frame, identified from logged data, in the Kalman filter of §9 and in the LQR of §11.
- A calibration of the camera for the scale from pixels to meters, now taken from the radius of the ball.
- A more realistic simulation, which would improve the performance of the RL policy on the robot, followed by a phase of fine tuning on the robot itself.

**New tasks**

- Tracking of a moving target, such as a circle or a figure eight, which requires the more precise actuation above.
- Use of the height $h$, the third degree of freedom of the platform, fixed at 120 mm in §6: to soften the landing of a ball, as in the catch at the top of this page, or to bounce it.

## 15. Credits

This project is a reproduction of the ball balancing robot built by [Koshiro Robot Creator](https://www.youtube.com/watch?v=KnYSuQEBGHc). I decided to build my own version mainly to experiment and to learn, but also because I did not have the motors used in the original one: every part has therefore been modeled from scratch, taking inspiration from his design. The only exception is `camera_cover.stl`, which is a modified version of the one published in his [GitHub repository](https://github.com/KoshiroRobot/Ball-Balancing-Robot).

The case that hosts the Raspberry Pi is the [Raspberry Pi 4 case](https://www.printables.com/model/566196-raspberry-pi-4-case) designed by Ryzor_Drone, modified so that it also works as the foot of the robot. That model is licensed under [CC BY-NC-SA 4.0](https://creativecommons.org/licenses/by-nc-sa/4.0/), so `raspberry_bottom.stl` and `raspberry_top.stl` are shared under the same license. The other parts, `camera_cover.stl` apart, are modeled from scratch and are not covered by it.

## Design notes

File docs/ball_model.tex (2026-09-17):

\documentclass[border=6pt]{standalone}
\usepackage{tikz}
\usetikzlibrary{arrows.meta,calc}
% Okabe-Ito palette, readable by colour blind viewers
\definecolor{cg}{HTML}{E69F00}
\definecolor{cn}{HTML}{009E73}
\definecolor{cf}{HTML}{0072B2}
\definecolor{ca}{HTML}{D55E00}
\definecolor{cacc}{HTML}{CC79A7}
\begin{document}
\begin{tikzpicture}[
  force/.style={-{Stealth[length=2.6mm]}, line width=1.2pt},
  axis/.style={-{Stealth[length=2mm]}, line width=0.6pt},
  thin/.style={line width=0.5pt}
]
\def\th{20}
\def\L{7.2}
\def\R{0.9}
\def\s{4.0}
% incline
\draw[line width=0.8pt] (0,0) -- ({\L*cos(\th)},0) -- ({\L*cos(\th)},{\L*sin(\th)}) -- cycle;
\draw[thin] (1.1,0) arc (0:\th:1.1);
\node at ({1.42*cos(\th/2)},{1.42*sin(\th/2)}) {$\theta$};

\begin{scope}[rotate=\th]
  \coordinate (c) at (\s,\R);
  \coordinate (p) at (\s,0);
  % axes
  \draw[axis] (0.7,0.3) -- ++(1.0,0) node[below right=-2pt] {$x$};
  \draw[axis] (0.7,0.3) -- ++(0,1.0) node[above left=-2pt] {$y$};
  % ball
  \draw[line width=0.8pt, fill=white] (c) circle (\R);
  \fill (c) circle (1.2pt);
  \draw[thin] (c) -- ($(c)+(15:\R)$) node[midway, above=-1pt] {$R$};
  % accelerations
  \draw[axis, ca, line width=0.9pt] ($(c)+(115:{\R+0.3})$) arc (115:205:{\R+0.3});
  \node[ca] at ($(c)+(160:{\R+0.65})$) {$\alpha$};
  \draw[force, cacc] ($(c)+({\R+0.25},0)$) -- ++(1.0,0) node[above] {$a$};
  % forces
  \draw[force, cg] (c) -- ($(c)+(250:1.75)$) node[right] {$m g$};
  \draw[force, cn] (c) -- ++(0,1.5) node[above] {$F_N$};
  \draw[force, cf] (p) -- ++(1.2,0) node[below right=-1pt] {$f_s$};
\end{scope}
\end{tikzpicture}
\end{document}

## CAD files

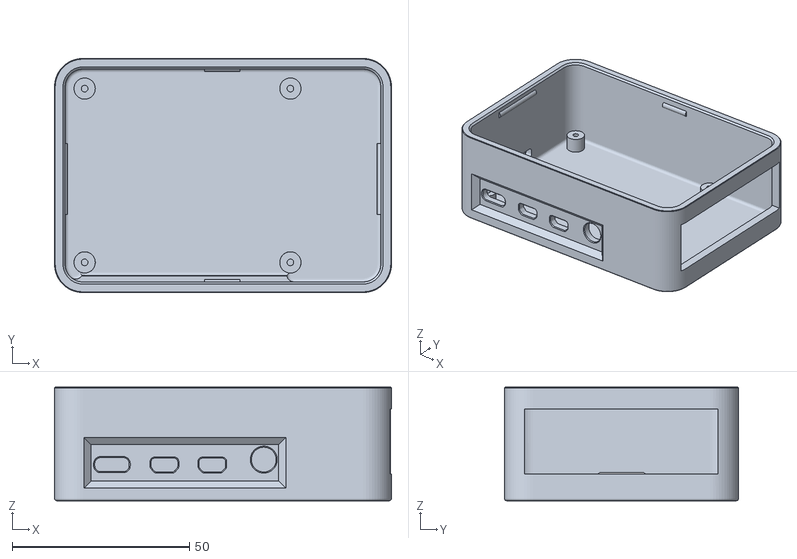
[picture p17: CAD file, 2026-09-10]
3d files/raspberry_bottom.stl
95.0 x 66.0 x 32.0

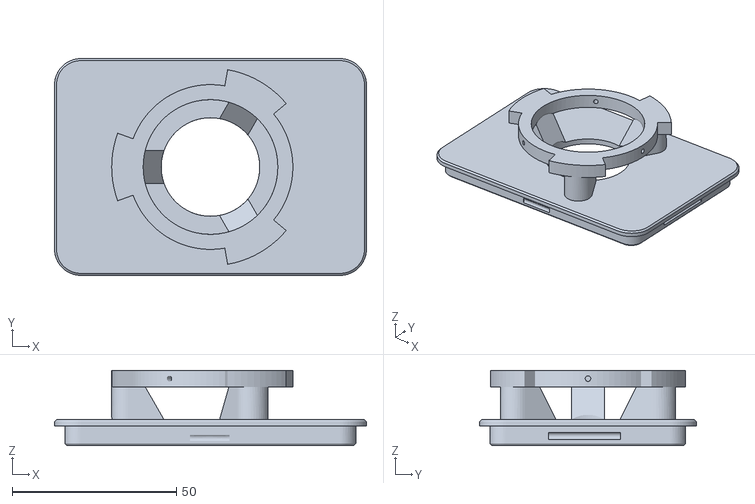
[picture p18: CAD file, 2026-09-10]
3d files/raspberry_top.stl
95.0 x 66.0 x 22.9

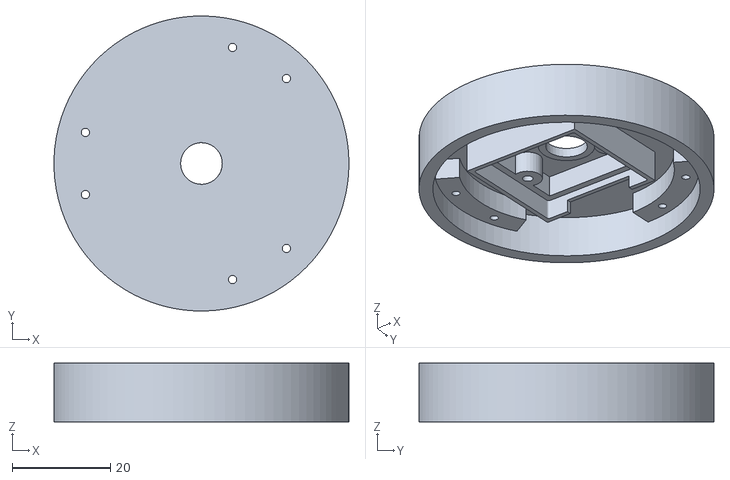
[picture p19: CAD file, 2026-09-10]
3d files/camera_cover.stl
60.1 x 60.2 x 12.0

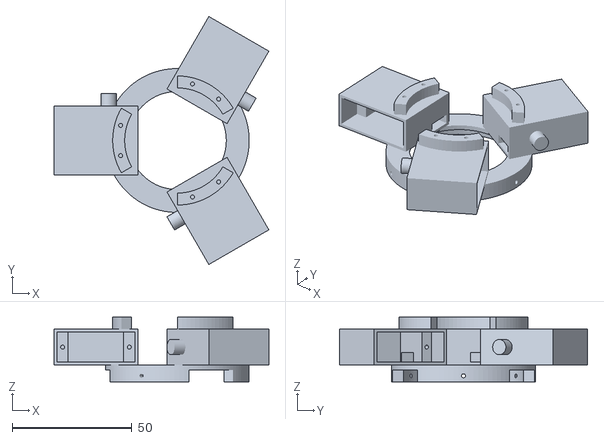
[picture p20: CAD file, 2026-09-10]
3d files/motor_base.stl
89.8 x 103.7 x 27.0

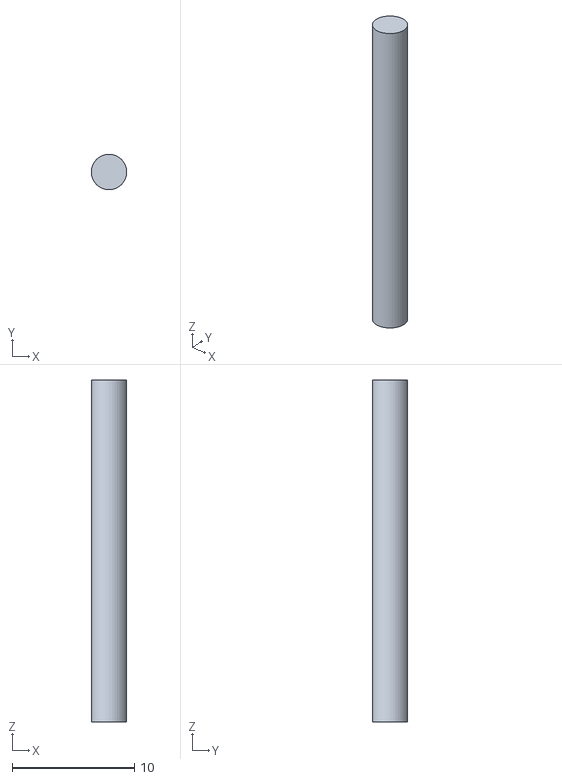
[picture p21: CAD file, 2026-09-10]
3d files/link_lower_connector.stl
2.90 x 2.90 x 28.0

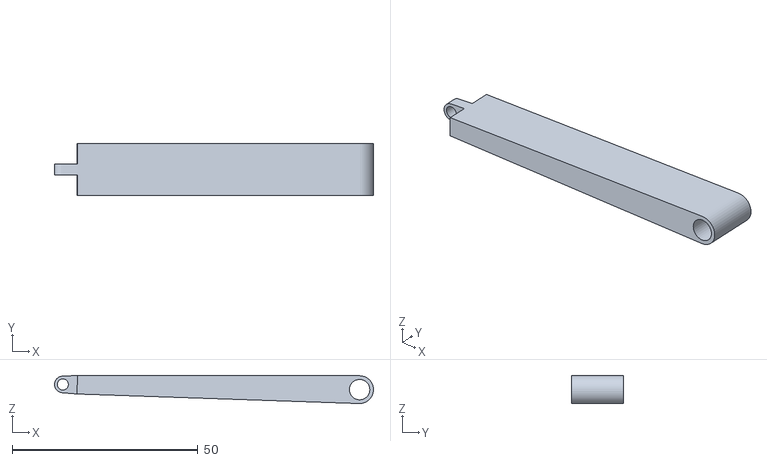
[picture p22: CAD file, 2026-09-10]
3d files/link_upper.stl
86.0 x 14.0 x 7.58

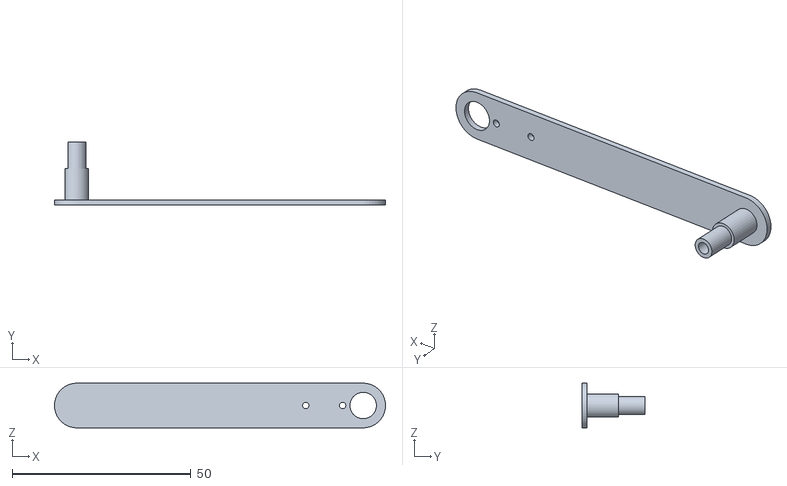
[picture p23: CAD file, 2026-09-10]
3d files/link_lower_half.stl
92.5 x 17.7 x 12.5

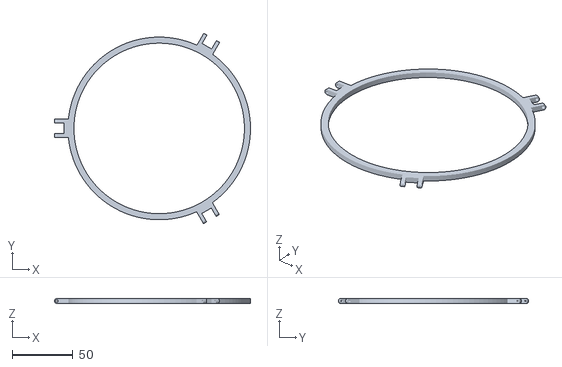
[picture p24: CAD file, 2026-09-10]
3d files/plate.stl
161.0 x 156.4 x 4.00

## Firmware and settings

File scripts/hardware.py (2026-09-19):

# Everything that talks to the Raspberry Pi: the three servos and the camera.

from picamera2 import Picamera2
import pigpio
import time

# ACTUATION SETUP
SERVO_PINS = [13, 18, 12]
OFFSETS = [0, -5, -5]
Q_HOME = 60                              # motor angle at the nominal pose
Q_RANGE = 15                             # travel allowed around the nominal pose
Q_MIN, Q_MAX = Q_HOME - Q_RANGE, Q_HOME + Q_RANGE

# CONNECT PIGPIO
pi = pigpio.pi()
if not pi.connected:
    raise RuntimeError("pigpio daemon not running. Start with: sudo pigpiod")

def angle_to_pulse(angle):
    # 0..180 deg -> 500..2500 us
    return 500 + (angle / 180.0) * 2000

def set_angle(angles):
    for i in range(3):
        pi.set_servo_pulsewidth(SERVO_PINS[i], angle_to_pulse(angles[i]))

def home():
    set_angle([Q_HOME + OFFSETS[i] for i in range(3)])

# CAMERA SETUP
TARGET_FPS = 20                   # frame rate demanded of the sensor
FRAME_US = int(1e6 / TARGET_FPS)  # the frame duration it corresponds to, in us

def start_camera(W, H):
    picam2 = Picamera2()          # start the frame capturing
    config = picam2.create_preview_configuration(
        main={"size": (W, H), "format": "RGB888"},
        controls={"FrameDurationLimits": (FRAME_US, FRAME_US)}
    )
    picam2.configure(config)
    picam2.start()
    time.sleep(1.0)
    return picam2

def shut_down(picam2):
    picam2.stop()
    for pin in SERVO_PINS:
        pi.set_servo_pulsewidth(pin, 0)
    pi.stop()

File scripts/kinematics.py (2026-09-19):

# Inverse kinematics: plate tilt in, motor angles out. See the matlab.

import numpy as np

# INVERSE KINEMATICS CONSTANTS
R_base = 28.65                           # radius of the base
R_plane = 84.00                          # radius of the plate
L1 = 80.0                                # length of link 1 (upper Pi -> Bi)
L2 = 80.0                                # length of link 2 (lower Mi -> Pi)
H_NOM = 120.0                            # height of the plate center at the nominal pose
base_c = np.array([0.0, 0.0, 0.0])       # coordinates of the base center
M1 = np.array([R_base*np.cos(np.pi),     R_base*np.sin(np.pi),     0.0]) # coordinates of motor 1
M2 = np.array([R_base*np.cos(5*np.pi/3), R_base*np.sin(5*np.pi/3), 0.0]) # coordinates of motor 2
M3 = np.array([R_base*np.cos(np.pi/3),   R_base*np.sin(np.pi/3),   0.0]) # coordinates of motor 3


# solve_P: given the coordinates of the motor (M) and of the ball joint (B),
# and the scalar factor that determines on which plane the pin joint must lie on (E),
# find the coordinates of the pin joint
def solve_P(M, B, E, sign):
    A = (L1**2 - L2**2 + (M[0]**2 - B[0]**2 + M[1]**2 - B[1]**2 + M[2]**2 - B[2]**2))/(2*(M[2] - B[2]))
    Bc = (B[0] - M[0])/(M[2] - B[2])
    Cc = (B[1] - M[1])/(M[2] - B[2])
    a_coef = 1 + E**2 + (Bc + Cc*E)**2
    b_coef = -2*B[0] - 2*E*B[1] + 2*(Bc + Cc*E)*(A - B[2])
    c_coef = B[0]**2 + B[1]**2 + (A - B[2])**2 - L1**2
    Px = (-b_coef + sign*np.sqrt(b_coef**2 - 4*a_coef*c_coef))/(2*a_coef)
    return np.array([Px, E*Px, A + (Bc + Cc*E)*Px])


# solve: given the control action u and the height of the plate, find the three
# motor angles in degrees. Returns None if the requested pose is not reachable.
def solve(u, h):
    n = np.array([u[0], u[1], 1.0]) # from the control action (negative gradient) we can compute the normal
    n = n / np.linalg.norm(n)

    # BALL JOINTS POSITION in direct form in h and n
    B1 = np.array([
        -n[2]*R_plane/np.sqrt(n[0]**2 + n[2]**2),
        0.0,
        h + n[0]*R_plane/np.sqrt(n[0]**2 + n[2]**2)
    ])
    B2 = np.array([
        n[2]*R_plane/np.sqrt(4*n[2]**2 + (n[1]*np.sqrt(3) - n[0])**2),
        -np.sqrt(3)*n[2]*R_plane/np.sqrt(4*n[2]**2 + (n[1]*np.sqrt(3) - n[0])**2),
        h + R_plane*(n[1]*np.sqrt(3) - n[0])/np.sqrt(4*n[2]**2 + (n[1]*np.sqrt(3) - n[0])**2)
    ])
    B3 = np.array([
        n[2]*R_plane/np.sqrt(4*n[2]**2 + (n[1]*np.sqrt(3) + n[0])**2),
        np.sqrt(3)*n[2]*R_plane/np.sqrt(4*n[2]**2 + (n[1]*np.sqrt(3) + n[0])**2),
        h - R_plane*(n[1]*np.sqrt(3) + n[0])/np.sqrt(4*n[2]**2 + (n[1]*np.sqrt(3) + n[0])**2)
    ])

    # REACHABILITY CHECK
    dist1 = np.linalg.norm(B1-M1)
    dist2 = np.linalg.norm(B2-M2)
    dist3 = np.linalg.norm(B3-M3)
    ok = (abs(L1-L2) < dist1 < L1+L2 and abs(L1-L2) < dist2 < L1+L2 and abs(L1-L2) < dist3 < L1+L2)
    if not ok:
        return None

    # PIN JOINTS
    P1 = solve_P(M1, B1, 0.0, -1)
    P2 = solve_P(M2, B2, -np.sqrt(3), +1)
    P3 = solve_P(M3, B3, np.sqrt(3), +1)

    # MOTOR ANGLES
    q1 = np.arctan(np.sqrt((P1[1]-M1[1])**2 + (P1[0]-M1[0])**2)/abs(P1[2]-M1[2]))
    q2 = np.arctan(np.sqrt((P2[1]-M2[1])**2 + (P2[0]-M2[0])**2)/abs(P2[2]-M2[2]))
    q3 = np.arctan(np.sqrt((P3[1]-M3[1])**2 + (P3[0]-M3[0])**2)/abs(P3[2]-M3[2]))
    return np.degrees([q1, q2, q3])

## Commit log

2026-09-08 Initial commit. File matalb with inverse kineamtics and PID control
    [3dprints.3mf]
2026-09-10 Renamed matlab inverse kinematics file. Added some docoumentation in the README
2026-09-10 Added 3d stl files. Completed the section of the README regarding inverse kinematics
    [3dprints.3mf, camera_cover.stl, link_lower_half.stl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]
2026-09-10 Removed and renamed some stl files. Updated the Mechanical design and Electronic section of the README
    [link_lower_connector.stl, little_perno.stl, plate.stl]
2026-09-10 Continued documentation with the README with the circuit schematics. Updated PID weights.
2026-09-17 Introduced the Kalman Filter. Fixed 20 FPS across the project
    [ball_balancer.py, control.py, hardware.py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]
2026-09-17 Fixed the pinkish window
    [vision.py]
2026-10-03 Updated README with RL and metrics evaluation
    [log_lqr_20261003_120058.csv, log_pid_20261003_115916.csv, log_rl_20261003_120218.csv]
